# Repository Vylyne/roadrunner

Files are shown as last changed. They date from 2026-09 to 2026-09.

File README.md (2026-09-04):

# Roadrunner: a high resolution filament motion sensor

Preview

## Contents

- [Features](#features)
- [TODO](#todo)
- [Build guide](#build-guide)
- [Klipper installation](#klipper-installation)
- [Configuration](#configuration)
- [Usage](#usage)

## Features

- [x] High-resolution, sub-millimetre motion detection
- [x] Direction detection for extrusion and retraction
- [x] Filament-presence detection and NeoPixel status indication
- [x] UART, I2C, and USB-serial sensor transports
- [x] Klipper runout, under-extrusion, and calibration support
- [x] Persistent provisioned device identities with safe USB diagnostics
- [x] Direct USB maintenance and ROM BOOTSEL recovery
- [x] A board without a valid identity refuses to serve sensor data

Provisioned USB serials use the `RR-<26 base32 UUID>` namespace. An ordinary
UF2 update preserves the identity record; the direct-USB `CLEAR_IDENTITY`
maintenance command is the only way to clear it.

**A Roadrunner serves no sensor data on any transport — I2C, UART, or USB —
until it has a valid identity. This is by design**, not a bug: it is the
invariant that keeps every provisioning path safe to use without its own
hand-written guard (see `docs/roadrunner-identity-gate-design.md`). A board
that is flashed and never provisioned, or whose identity record cannot be
trusted (a conflicting or unreadable record, not only an absent one), is
inert; on I2C and UART it announces this with a short amber LED burst every
30 seconds, and the absence of that burst on the next boot after
provisioning is the confirmation it worked. If your Roadrunner "does not
work" after flashing, provision it first.

Every provisioning path is built on the same firmware primitive: the direct
USB admin `PROVISION_UUID` opcode, which works today on all six firmware
images (see [`docs/roadrunner-usb-admin-protocol.md`](docs/roadrunner-usb-admin-protocol.md)).
There are four intended ways to reach it:

- mcu-updater, opt-in automatic provisioning
- mcu-updater, manual provisioning
- a standalone USB provisioning script (planned; see
  `docs/roadrunner-identity-gate-design.md`)
- the Klippy extra, on connect, when opted in — for an I2C- or UART-wired
  Klipper install, over the board's usbserial admin connection

There is no provisioning write path on I2C or UART yet, so **an I2C-only or
UART-only installation needs a USB cable once**, even when using the Klippy
extra's on-connect path — every route above ultimately goes over USB.

## TODO

- [ ] Add GitHub Actions firmware build and release artifacts, plus repeatable
  protocol validation on a bench board.

Most 3D printer motion sensors are bulky, slow to trigger, prone to false positives, and have a high detection distance meaning a large amount material is extruded before actually detecting a runout, leading to poor layer adhesion and failed prints after a runout.

The Roadrunner motion sensor is based on a magnetic rotary encoder which can detect sub-millimeter movement in the filament for accurate extrusion length measurement, in addition to an IR sensor which can instantly detect filament runout. With the combination of both sensors and a dedicated RP2040-Zero board for collecting data, the Roadrunner can detect which type of issue is affecting a print, between simply reaching the end of a spool, the filament no longer moving, or the filament moving but at a lower than expected rate of extrusion.

By leveraging the higher precision of the sensor, it's possible to determine the length, speed and volumetric flow that are expected and compare them to the actual measured values in real time which gives us a reasonable approximation of _how much_ the filament is being under-extruded by. A simple to use `CALIBRATE_MAX_FLOW` command is provided to perform free-air extrusion tests and automatically benchmark the maximum volumetric flow of any temperature/nozzle/material combination.

## Build guide

This is an open-source project, so you can build your own!

See the [bill of material](manual/BOM.md) and the [assembly manual](manual/ASSEMBLY.md).

## Klipper installation

Clone the repository and create a symlink to the sensor code:

```
cd ~
git clone --depth 1 --single-branch https://github.com/Vylyne/roadrunner.git roadrunner-filament-sensor
~/roadrunner-filament-sensor/install.sh
```

Restart klipper for the new sensor type to be recognized:
```
sudo service klipper restart
```

To get automatic updates within moonraker, add the following block at the end of `moonraker.conf`:
```ini
[update_manager roadrunner-filament-sensor]
type: git_repo
path: ~/roadrunner-filament-sensor
origin: https://github.com/Vylyne/roadrunner.git
install_script: install.sh
primary_branch: main
managed_services: klipper
```

## Configuration

Add the following configuration to your `printer.cfg`:

```
[high_resolution_filament_sensor roadrunner]
extruder: extruder
#  The extruder to which this sensor is attached
uart_rx_pin: P0.0
uart_tx_pin: P0.1
#  TX and RX pins for UART communication, leave out if i2c or USB serial is used (see below).
#i2c_address: 64
#  The address of the sensor on the I2C bus, the default is 64 (0x40). Only
#  change this if you attach more than one sensor on the same I2C bus.
#i2c_mcu: mcu
#  The mcu on which the sensor is connected.
#i2c_bus: i2c1
#  The I2C bus to which the sensor is connected on the mcu.
#serial: /dev/serial/by-id/usb-Raspberry_Pi_Pico_E66130100F655734-if00
#  The serial port over which the sensor is connected. Find with `ls -alh /dev/serial/by-id`.
pause_on_runout: False
#  Whether or not to pause the print automatically when a runout
#  condition is triggered.
runout_gcode: RESPOND TYPE=command MSG='Filament runout detected'
#  The gcode to execute when a runout condition is detected.
invert_direction: False
# If the measured distance/speed values are negative, change this to True.
rotation_distance: 23.4
# The length of filament which corresponds to a full 360 degree rotation
# of the magnet over the rotary encoder. A good starting point is the
# circumference of the BMG gears in the sensor.
underextrusion_max_rate: 0.5
# What rate of underextrusion can be tolerated, as a value between 0.0 and 1.0.
# The rate is calculated by comparing the extruder position to the measured
# filament length over a certain period. A rate of 0.0 means the measured
# filament motion matches the expected extrusion distance over the period.
# A rate of 1.0 means no filament motion was detected at all when some motion
# was expected for the extruder.
underextrusion_period: 5
# How long should the underextrusion rate stay above the max rate before
# a runout is triggered.
hysteresis_bits: 3
# How many bits to ignore from the magnetic rotary encoder's angle data.
# This setting determines the minimum detectable change in position
# for the sensor. Configuring this too low can result in flapping between
# two adjacent positions even when the filament is not moving.
```

Two virtual pins are created for each sensor, which can be used to configure a [`filament_motion_sensor`](https://www.klipper3d.org/Config_Reference.html#filament_motion_sensor) or a [`filament_switch_sensor`](https://www.klipper3d.org/Config_Reference.html#filament_switch_sensor). This is mainly for convenience of use with user interfaces like mainsail/fluid. The virtual motion sensor will be triggered as soon as the sensor moves by the minimum detectable distance. The switch sensor will trigger when the IR sensor detects the filament is present. Both objects will work independently of the runout detection algorithm implemented in `high_resolution_filament_sensor` which considers additional factors such as underextrusion.

An example configuration would look like:

```
[filament_motion_sensor roadrunner_motion]
detection_length: 2
extruder: extruder
switch_pin: virtual_motion_sensor:roadrunner
pause_on_runout: False
runout_gcode: RESPOND TYPE=command MSG='Filament motion sensor detected a runout'
event_delay: 0.1

[filament_switch_sensor roadrunner_switch]
switch_pin: virtual_switch_sensor:roadrunner
pause_on_runout: False
runout_gcode: RESPOND TYPE=command MSG='Filament switch sensor detected filament is no longer present'
event_delay: 0.1
```

## Usage

##### Calibration cheat sheet

Here's an example of a complete calibration workflow:

```
# Disable a few things for these tests
SET_PRESSURE_ADVANCE EXTRUDER=extruder ADVANCE=0
SET_Z_THERMAL_ADJUST TEMP_COEFF=0 ENABLE=0

# Optionally home the printer and move to a safe Z
G32
G0 Z100

# Check your sensor info
QUERY_FILAMENT_SENSOR SENSOR=roadrunner

# Find rotation_distance value, don't forget to save it in the sensor config & restart.
CALIBRATE_FILAMENT_SENSOR_ROTATION_DISTANCE SENSOR=roadrunner TEMP=250 LENGTH=30 SPEED=30 COUNT=10

# Find max flow for this extruder, save the graph of collected data for future reference (THIS WILL TAKE A WHILE)
CALIBRATE_MAX_FLOW SENSOR=roadrunner TEMP=250 START=1 STOP=40 SAVE_GRAPH=1

# Measure a G1 command at a high speed (e.g. 11.5mm/s = 690mm/m).
# Use a value that will produce a flow in the non-linear part of the curve in the previous graph.
FILAMENT_SENSOR_MEASURE SENSOR=roadrunner TEMP=250 SPEED=690 LENGTH=100 SAVE_GRAPH=1

# Enable nonlinear extrusion with coefficients suggested by `CALIBRATE_MAX_FLOW`
ENABLE_NONLINEAR_EXTRUSION SENSOR=roadrunner ENABLE=1 COEFFICIENTS=-0.1106867,1.1197162,-0.0347608,0.0028625

# Take same measurement again, the measured length and speed should show little deviation.
FILAMENT_SENSOR_MEASURE SENSOR=roadrunner TEMP=250 SPEED=690 LENGTH=100 SAVE_GRAPH=1

# Now check the result of the extrusion compensation by generating a new graph (THIS WILL TAKE A WHILE)
CALIBRATE_MAX_FLOW SENSOR=roadrunner TEMP=250 START=1 STOP=40 STEP=2 COUNT=2 SAVE_GRAPH=1
```

##### Calibrate the sensor's rotation distance:

The first thing to do is to calibrate the `rotation_distance` for the sensor itself. This is done
with `CALIBRATE_FILAMENT_SENSOR_ROTATION_DISTANCE`:

```
CALIBRATE_FILAMENT_SENSOR_ROTATION_DISTANCE SENSOR=roadrunner TEMP=250 LENGTH=30 SPEED=60 COUNT=10
```

* `TEMP`: The temperature to heat up the extruder heater at. Default is 200.
* `LENGTH`: The length of filament to retract. Default is 25.
* `SPEED`: The extrusion speed, in rotation per minute (e.g. 300 means 5mm/s). Default is 30 (0.50mm/s).
* `COUNT`: How many times to perform the test. Default is 10.

This macro will heat up the extruder heater to the specified temperature, retract the filament multiple times,
and calculate some stats. The measurement is done while retracting the filament to avoid introducing an error
due to the back-pressure in the nozzle. Make sure a length of filament at least `LENGTH` mm long can
be retracted while still being gripped by the extruder gears. For best results, perform this test at low
speed over a distance long enough for the sensor's gears can do one full rotation.

After the distance measurements are taken, they are sorted by frequency and the measurement with the highest frequency is used to calculate a new `rotation_distance`. For example, if 8/10 measurements read 25.62mm when 25mm was expected, the `rotation_distance`
was too high and a new value is automatically suggested. After saving the new `rotation_distance` in your sensor configuration, repeating the test with the same macro parameters should measure the correct distance. The deviation between measurements is reported relative to the minimum detectable change in position, a small deviation indicates repeatable measurements. While the sensor is
high precision, its accuracy and repeatability over multiple readings can be affected by real world factors such as
springiness in the PTFE tube, the attachement of the sensor to the body of the extruder, etc.

Preview

##### Measure a G1 command

Extrude some filament using a G1 command, and print the result as measured by the sensor.

```
FILAMENT_SENSOR_MEASURE SENSOR=roadrunner TEMP=250 LENGTH=10 SPEED=120 COUNT=1
```

* `TEMP`: The temperature to heat up the extruder heater at. Default is 200.
* `LENGTH`: The length of filament to retract. Default is 10.
* `SPEED`: The extrusion speed, in rotation per minute (e.g. 300 means 5mm/s). Default is 120 (2mm/s).
* `COUNT`: How many times to perform the test. Default is 1.
* With the `SAVE_GRAPH=1` parameter, a graph of all measurements is saved to klipper's current working directory (usually `~/klipper/`).

The macro will run one or more G1 command until the desired length of filament is extruded. The macro will print stats for each move, as measured by the sensor.

Optionally if a graph is saved, the output will look like this:

Preview

##### Max flow calibration

The goal of this macro is to help determine the maximum volumetric flow for a given combination of filament, nozzle and temperature. Before starting, make sure your extruder's `filament_diameter` is correct, as well as the filament sensor's `rotation_distance`. For best results, the `STOP` value should be above or near the top of your extruder's expected maximum volumetric flow rate.

```
CALIBRATE_MAX_FLOW SENSOR=roadrunner TEMP=250 START=1 STOP=50 SAVE_GRAPH=1
```

* `TEMP`: The temperature to heat up the extruder heater at. Default is 200.
* `DURATION`: How long to extrude for during each test, used to determine the extrusion length (length = speed * duration). Default is 10 seconds.
* `START`: The minimum volumetric flow to test. Default is 5.
* `STOP`: The maximum volumetric flow to test. Default is 25.
* `STEP`: The amount by which to increment the volumetric flow between each test. Default is 1.
* `COUNT`: How many times to perform the test for each volumetric flow value. Default is 5.
* `MAX_SPEED_DEVIATION`: The percentage of deviation between the expected and the measured speed that will be considered acceptable. Used for recommending a maximum volumetric flow. Default is 0.05 (5%).
* With the `SAVE_GRAPH=1` parameter, a graph of all measurements is saved to klipper's current working directory (usually `~/klipper/`).

Preview

This macro will warn when a given volumetric flow was so high that not all measurements could be taken at this rate. This often corresponds to the physical limit of the extruder, where the back-pressure is so high that the extruder cannot keep up and eats into the filament.

After the measurements are taken, this macro will look for a range of speeds where the deviation between the expected and measured speeds is below `MAX_SPEED_DEVIATION` percent. At higher speeds, the back-pressure in the nozzle will cause under-extrusion, this can be identified visually in the data graph (use `SAVE_GRAPH=1`) as a part of the curve where the exected and measured speeds start deviating sharply. A polynomial curve is fitted to the relationship between the expected vs measured speeds, which can be used to compensate for the under-extrusion at higher speeds.

Optionally if a graph is saved, the output will look like this:

Preview

##### Enable non-linear extrusion compensation (EXPERIMENTAL)

A `[non_linear_extrusion]` config section must be added for this command to work with a given extruder:
```
[non_linear_extrusion t0]
extruder: extruder
# Name of the extruder for which nonlinear extrusion compensation can optionally
# be enabled.
```

When non-linear extrusion compensation is enabled, the increase in pressure in the extruder will be compensated by increasing the requested speed of G1 commands. This applies to both extrude-only moves as well as regular printing moves. The compensation is only applied when using relative coordinates and only when a positive E distance is specified since retraction moves are not affected by pressure in the nozzle.

```
ENABLE_NONLINEAR_EXTRUSION EXTRUDER=extruder ENABLE=1 COEFFICIENTS=-0.1106867,1.1197162,-0.0347608,0.0028625
```

* `ENABLE`: 1 to enable, 0 to disable
* `COEFFICIENTS`: A list of comma-separated polynomial coefficients.

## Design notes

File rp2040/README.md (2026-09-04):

# Roadrunner RP2040-zero Firmware

## Dependencies

```sh
sudo apt install cmake gcc-arm-none-eabi libnewlib-arm-none-eabi libstdc++-arm-none-eabi-newlib
```

## Configuring

Some neopixels have RGB color ordering while others have GRB. When the filament is inserted the LED should ligth green, if it is RED then you should use the GRB ordering. Uncomment the following line in `neopixel.h` and re-run `make` to build the firmware.

```c
#define GRB_LED_ORDER 1
```

## Building

```sh
git clone https://github.com/Vylyne/roadrunner.git roadrunner-filament-sensor
cd roadrunner-filament-sensor
git submodule update --init --recursive
cd rp2040
mkdir build
cd build
cmake ..
make
```

You'll find multiple `.uf2` files in the `roadrunner-filament-sensor/rp2040/build` directory. The name contains `uart`, `i2c` or `usbserial` for the communication mode between mcu and sensor, and `rgb` vs `grb` for the neopixel type.

## Flashing

1. Connect RP2040-Zero to computer via USB
2. Press `BOOT` and `RESET` at the same time
3. Release `RESET` and 1 second later release `BOOT`
4. A drive named `RPI-RP2` will appear
5. Copy newly built `.uf2` file to the drive to flash the new firmware.

## LED indications

| Condition | Indication |
| --- | --- |
| board has no valid identity (`rr_identity_registers_locked()`) | amber, 50 ms blink half-period, for 1500 ms, repeating every 30000 ms, first burst at power-on |
| `magnet_state != MAGNET_STATE_DETECTED` | blink RED, 100 ms |
| `!filament_present` | solid BLUE |
| otherwise | solid GREEN |

The blink half-periods (50 ms amber, 100 ms RED) assume `CLOCKS_PER_SEC ==
100`, as provided by this toolchain — `neopixel.c` times blinking off its own
`clock()`, which ticks every 10 ms, via
`elapsed_since_blink() = (clock() - last) * 1000 / CLOCKS_PER_SEC`. A
toolchain supplying a different `CLOCKS_PER_SEC` would scale both rates
together, so the 2:1 ratio that makes the amber and RED blinks read as
different channels survives regardless.

The amber burst applies to any board without a valid identity, not only one
that was never provisioned — a conflicting or unreadable identity record
locks the board the same way. It is checked first in the LED chain, so it
overrides the diagnostic indications while active, and yields the LED
entirely between bursts. It exists because the bring-up procedure reads the
LED for minutes at a time — load filament, read BLUE, trim the lever arm,
read BLUE, trim again, until GREEN — so a boot-only announcement would be
missed and a continuous one would fight the readout somebody is actually
using. A short burst on a long period is seen several times without ever
obscuring it.

The first burst is shorter than the rest: firmware init holds a solid RED for
about 1.1 seconds (a 100 ms neopixel settle plus a 1000 ms sensor-init delay)
before the LED chain is reached for the first time, so only the tail of the
first 1500 ms window is visible — roughly 400 ms of amber, not the full
1500 ms. Every burst after that is the complete 1500 ms, since the burst
window is timed from power-on rather than from when the LED chain starts
running.

Because `PROVISION_UUID` resets the board, **the absence of amber on the next
boot is the provisioning success confirmation** — observable with no host, no
tool, and no serial console. For an I2C-only user running an unpatched vendor
extra, that is the entire feedback loop.

## Device identity and USB maintenance

Each image reserves the final flash sector for a persistent Roadrunner device
identity. The ROM BOOTSEL serial and the flash-derived USB ID are diagnostics,
not persistent identities.

Provisioned USB serials use the `RR-<26 base32 UUID>` namespace. An ordinary
UF2 update preserves the identity record; the direct-USB `CLEAR_IDENTITY`
maintenance command is the only way to clear the reserved-sector record. See
[`../docs/roadrunner-usb-admin-protocol.md`](../docs/roadrunner-usb-admin-protocol.md)
for the complete byte-level contract and updater rules.

Maintenance commands are available only over Roadrunner's directly connected
USB CDC port. They are never forwarded over I2C, UART, or a Klipper sensor
transport. The legacy USB sensor-register stream beginning with `0xf5`
continues unchanged.

The maintenance frame is:

```
0x52 0x52 0x01 opcode payload_length payload crc8
```

`crc8` is CRC-8/ATM over every preceding byte (polynomial `0x07`, initial
value `0x00`, no reflection, final XOR `0x00`). `INFO` is opcode `0x01`,
`REBOOT_BOOTSEL` is opcode `0x02`, `PROVISION_UUID` is opcode `0x03`, and
`CLEAR_IDENTITY` is opcode `0x04`; responses set bit `0x80` in the opcode.
The status values are `0x00` OK, `0x01` bad CRC, `0x02` bad length, `0x03`
unprovisioned, `0x04` already provisioned, `0x05` identity conflict, `0x06`
identity-store I/O error, and `0x07` confirmation required. `0x03` is
overloaded: it is both the `INFO` status meaning "no valid identity stored"
and the refusal a locked board returns for an opcode that requires one — see
[`../docs/roadrunner-usb-admin-protocol.md`](../docs/roadrunner-usb-admin-protocol.md#status-03-has-two-roles)
for which opcodes are gated and why `CLEAR_IDENTITY`'s gate is not symmetric
with `REBOOT_BOOTSEL`'s.

An `INFO` request has an empty payload. Its response payload is exactly:

1. status;
2. identity-store state (`0` none, `1` provisioned, `2` conflict, `4` I/O
   error — this reports `rr_identity_load()`'s result; `3` already
   provisioned is part of the enum but is only returned by
   `rr_identity_provision()`, so INFO never reports it);
3. transport (`1` I2C, `2` UART, `3` USB);
4. LED order (`1` RGB, `2` GRB);
5. model length and ASCII model (`roadrunner-v1`);
6. firmware-version length and ASCII version (the CMake
   `ROADRUNNER_FIRMWARE_VERSION`, default `dev`);
7. serial length and ASCII serial; and
8. eight raw flash-UID bytes.

`REBOOT_BOOTSEL` has an empty payload. After the successful ACK is written,
the firmware flushes and waits for TinyUSB's transmit-completion callback and
an empty CDC transmit FIFO, then invokes the RP2040 ROM handoff
`reset_usb_boot(0, 0)`. The same physical USB connection
must then enumerate as the `RPI-RP2` mass-storage device. Copy the matching
UF2 and reconnect to query `INFO` again.

`PROVISION_UUID` has a 16-byte UUID payload. It writes the record only when
the identity store is erased, then returns `OK`, a serial length, and the
new `RR-<26 base32 UUID>` serial. `CLEAR_IDENTITY` has the four-byte ASCII
payload `RRCL`; any other four-byte payload returns `confirmation required`
without changing the store. Successful provision and clear responses are
flushed and transmitted completely before the application resets and the CDC
device re-enumerates. INFO and all error/refusal responses do not reset. On
restart,
the USB descriptor reloads the stored identity and presents the same newly
provisioned serial (or the unprovisioned fallback after a clear).

If the maintenance command is unavailable, use the manual fallback: hold
`BOOT`, press and release `RESET`, release `BOOT` after one second, then copy
the matching UF2 to `RPI-RP2`. Use only a bench RP2040-Zero with a known
recovery path for this procedure.

## Bench validation

On a bench RP2040-Zero, the direct USB BOOTSEL command was verified for the
USB-serial, I2C, and UART images in both RGB and GRB variants. Every image
returned the complete ACK `52 52 01 82 01 00 5a` before the board re-enumerated
as `RPI-RP2`. The USB-serial GRB image also returned a complete legacy
`0xf5 0x10` register-read frame, confirming the maintenance parser preserves
the sensor protocol. Provisioning, clear, UF2-retention, and refusal
behavior were validated against the dedicated bench matrix in the protocol
reference on a recoverable RP2040-Zero on 2026-09-02: all six RGB/GRB
transport images reported the correct INFO transport and LED order, retained
their serial across an ordinary UF2 update, and successfully cleared and
reprovisioned a new serial; both USB-serial images also returned the legacy
`F5 10` response; a duplicate `PROVISION_UUID` was rejected with
`ALREADY_PROVISIONED` on all six images, and a bad clear confirmation was
rejected with `CONFIRMATION_REQUIRED` without rebooting. See
[`../docs/roadrunner-usb-admin-protocol.md`](../docs/roadrunner-usb-admin-protocol.md#bench-matrix)
for the full bench matrix and results.

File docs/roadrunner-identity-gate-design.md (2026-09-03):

# Roadrunner identity gate — design

Status: accepted, 2026-09-03.
Supersedes nothing; extends `roadrunner-provisioning-design.md` and
`roadrunner-usb-admin-protocol.md`, both of which remain authoritative for the
USB admin wire format and the identity namespace.

## Problem

Provisioning today is a policy enforced by hosts, not an invariant enforced by
the device. That policy has to be re-implemented, correctly, in every host that
touches a Roadrunner, and it has already produced four separate hazards:

1. **Flash UID is not unique.** Two Roadrunners built from the same batch report
   the same `pico_get_unique_board_id()`. Their unprovisioned serials therefore
   collide (`RR-UNPROVISIONED-<uid>`), which collides their
   `/dev/serial/by-id/usb-Vylyne_Roadrunner_<serial>-if00` symlinks. udev
   creates one. mcu-updater's `_entry_candidates()` lists that directory by
   name, so with two unprovisioned boards attached it sees **one**, and the
   "refuse ambiguous matches" guard never fires because no ambiguity is visible.
   Confirmed on hardware: provisioning the visible board made the second appear.

2. **Port freedom is not safety.** mcu-updater gates Roadrunner discovery on
   `needs_ports_free = True`. For the USB-serial variant that coincides with
   safety, because Klipper holds the port. For the I2C and UART variants it is
   *inverted*: the USB admin port reads free precisely because Klipper is
   driving the board over a different bus. `PROVISION_UUID` and
   `CLEAR_IDENTITY` both reset the device, so the current code can reset a board
   mid-print.

3. **Provisioning invalidates a `serial:` config line.** A USB-serial variant
   referenced in `printer.cfg` by its by-id path stops resolving the moment its
   serial changes. mcu-updater's `serial_add()` refuses unprovisioned serials,
   but that guard only covers mcu-updater's own registry — a hand-written
   `[high_resolution_filament_sensor]` section is not covered.

4. **"Untracked" carries no information.** Because `serial_add()` structurally
   forbids tracking an unprovisioned board, an unprovisioned Roadrunner is
   always untracked — whether it is on a bench or driving filament on a
   toolhead. mcu-updater's own registry cannot distinguish those cases.

Every one of these is a host compensating for a device that will happily work
without an identity.

## Decision

**A Roadrunner refuses to do its job until it is provisioned.**

The board keeps its autonomous behaviour — it reads the AS5600 and the IR
sensor, and it drives the neopixel. What it refuses is to *answer a host* about
any of it. The identity window and the provisioning path are the only things
available on a host transport until an identity exists.

This is safe to state as an invariant because the Roadrunner is a sensor with no
autonomous actuation. A variant that ever drives something on its own must
revisit it.

### What the invariant buys

- **Unprovisioned implies not live.** No unprovisioned board can be mid-print on
  any transport, so provisioning it can never interrupt one. `assert_printer_idle`
  narrows to what it should always have been: a guard on `CLEAR_IDENTITY` and
  `REBOOT_BOOTSEL` against *provisioned* boards.
- **Hazard 3 disappears at the source.** Nobody can have a working `printer.cfg`
  that references `RR-UNPROVISIONED-…`, because that board never worked.
  Provision-before-configure stops being advice and becomes the only path.
- **Hazard 1 stops mattering for safety.** Colliding unprovisioned serials are
  still a discovery nuisance (see "Still required" below) but no longer a
  correctness risk, because none of the colliding boards is doing anything.
- **All four provisioning paths become safe by construction**, so they can
  coexist without each one needing its own carefully-reasoned guard.

### The four provisioning paths

| Path | Population served | Transport |
| --- | --- | --- |
| mcu-updater, opt-in auto | mcu-updater users | USB admin |
| mcu-updater, manual | mcu-updater users | USB admin |
| `scripts/roadrunner_usb.py` (in mcu-updater) | USB wired, no mcu-updater | USB admin |
| klippy extra, on connect | Klipper-only | usbserial only, until the write path lands |

The USB admin layer is present on all six builds ({I2C, UART, USB} × {RGB, GRB}),
so the first three cover anyone with a USB cable attached.

**Correction, 2026-09-03.** An earlier version of this table claimed the fourth
path serves an I2C-only or UART-only installation with no USB cable, and called
that its reason for existing. That is wrong, and it contradicted this document's
own "Still required" section: neither `i2c_target.c` nor `tmcuart.c` has a write
path, so the klippy extra can provision over usbserial only. **An I2C-only or
UART-only installation needs a USB cable once**, until provisioning writes over
those transports are built. The fourth path still earns its place — it is the
route for a Klipper host with no mcu-updater — but not for the reason first
given.

## Firmware design

### The choke point

All three host transports already funnel through a single function:

```c
void prepare_register_data(uint8_t reg, uint8_t *buf, size_t *length);
```

- `i2c_target.c` calls it from `I2C_SLAVE_REQUEST`.
- `usbserial.c` calls it from `usbserial_send_response()`.
- `tmcuart.c` calls it from `tmcuart_send_response()`.

The gate therefore lives in exactly one place. No transport-specific policy.

### Refuse audibly, never go dark

An I2C target that stops ACKing looks like a wiring fault. A silent TMC-UART
looks like a dead board. Both send someone hunting hardware problems that do not
exist. The transport loops keep running unprovisioned, and a blocked read
**returns a response of the expected length, filled with `0xFF`**.

`0xFF` is out of range for almost every existing field: it is not a defined
`MAGNET_STATE_*`, and `0xFFFFFFFF` is not a plausible angle or turn count. An
unpatched vendor extra therefore reads *visibly broken*, not plausibly wrong —
which is the correct failure. A patched extra reads the identity-state register
and knows exactly why.

**One exception, and it is real:** `state.filament_present` is a `bool`, so
`0xFF` at `READ_FILAMENT_PRESENCE` (`0x22`) is *truthy*. A host reading that
register in isolation on a locked board sees "filament present" — plausibly
wrong, not visibly broken. This is accepted rather than fixed with a
per-register refusal value, because a table of per-field sentinels would be
more code, more to keep in step, and still not authoritative. The mitigations
are that `READ_ALL` carries `magnet_state = 0xFF` in the same payload, which
*is* out of range and which the vendor extra surfaces as `magnet_state`, and
that `READ_IDENTITY_STATE` is the authoritative answer any host is expected to
consult. The protocol doc must state the exception explicitly so nobody
concludes a locked board is reporting real filament.

Zero-length responses are explicitly rejected as a refusal encoding, and so is a
bare status byte: `0x03` collides with `MAGNET_STATE_TOO_STRONG` on a one-byte
register.

### Identity register window

A new register range, chosen to clear the existing sensor map (`0x10`,
`0x20`–`0x24`, with `0x20` reserved for the commented-out `READ_HEALTH`):

| Register | Name | Size | Content |
| ---: | --- | ---: | --- |
| `0x30` | `READ_IDENTITY_STATE` | 1 | `rr_identity_status_t` — 0 none, 1 ok, 2 conflict, 3 already provisioned, 4 I/O error |
| `0x31` | `READ_SERIAL` | 34 | ASCII, NUL-padded. `RR_USB_SERIAL_MAX_LENGTH` is 34; the longest real serial, `RR-UNPROVISIONED-<16 hex>`, is 33 |
| `0x32` | `READ_FIRMWARE_VERSION` | 32 | ASCII, NUL-padded |
| `0x33` | `READ_VARIANT` | 2 | transport byte, LED-order byte — same values as the USB `INFO` payload |
| `0x34` | `READ_FLASH_UID` | 8 | Raw diagnostic bytes. **Hosts must not persist this** |

These five registers are **always readable**, provisioned or not. They are the
unprovisioned allow-list and the steady-state identity source, and one
definition serves both — there is no separate "provisioning mode."

Field order and encoding mirror the USB `INFO` response deliberately, so
`roadrunner-usb-admin-protocol.md` stays the single source of truth for what a
Roadrunner's identity *is*, with `INFO` and this window as two encodings of it.

### Status `0x03` serves two roles

`RR_USB_ADMIN_UNPROVISIONED` (`0x03`) currently documents as "INFO status: no
valid identity is stored" — a state. It now also encodes a refusal, returned by
the USB admin layer for any opcode other than `INFO` and `PROVISION_UUID` while
unprovisioned. The protocol doc must say so, or a host reading `0x03` off a
blocked command misreads it as an `INFO` reply.

`CLEAR_IDENTITY` is refused only when the status is `RR_IDENTITY_NONE` — there
is genuinely nothing to erase. It is **not** gated on `status == RR_IDENTITY_OK`.

**`REBOOT_BOOTSEL` is not gated at all. Correction, 2026-09-03.** An earlier
version of this document put it in the refusal set while unprovisioned, arguing
"there is no reason to reflash a board that cannot be used." That reasoning is
backwards, and following it produced a genuine dead end.

`rr_identity_clear` refuses a conflicted sector outright —
`identity_store.c:74-76` returns `RR_IDENTITY_CONFLICT` before erasing, and
`tests/test_identity_record.c` asserts the sector is left byte-for-byte
unchanged. So a conflicted board cannot be repaired by `CLEAR_IDENTITY`. With
`REBOOT_BOOTSEL` also gated, such a board could do nothing over USB admin at
all: `INFO` answers, `PROVISION_UUID` returns `05`, `CLEAR_IDENTITY` returns
`05`, `REBOOT_BOOTSEL` returned `03`. Every software recovery path was closed.

A board that cannot be used is precisely the one you want to reflash. The gate
had no beneficial case — it fired only on `NONE`, `CONFLICT` and `IO_ERROR`,
and reflashing is the right action in all three. Reflashing is maintenance, not
"doing its job", so it was never inside the invariant this design exists to
enforce; normal UF2 updates preserve the identity sector, so it is not an
identity bypass; and the physical BOOTSEL button meant the gate only ever
blocked the convenient path, never a capable attacker.

The resulting opcode table:

| Opcode | `NONE` | `CONFLICT` | `IO_ERROR` | `OK` |
| --- | --- | --- | --- | --- |
| `INFO` | allowed | allowed | allowed | allowed |
| `PROVISION_UUID` | allowed | refused `05` (store) | store decides | refused `04` |
| `CLEAR_IDENTITY` | refused `03` | admitted, refused `05` by the store | store decides | allowed |
| `REBOOT_BOOTSEL` | allowed | allowed | allowed | allowed |

Note the two-stage behaviour of `CLEAR_IDENTITY`: the opcode gate admits it in
every state but `NONE`, and the *store* then decides. A conflicted sector is
never erased. `RR_IDENTITY_IO_ERROR` is recoverable only when the failure was at
the verify stage with reads still working (`identity_store.c:77-82`); a
read-failure `IO_ERROR` returns at `:70-72` without erasing. **`REBOOT_BOOTSEL`
is therefore the recovery path for a conflicted board**, which is the concrete
reason it must stay ungated.

### LED behaviour

Current main-loop behaviour, unchanged as the steady state:

| Condition | Indication |
| --- | --- |
| `magnet_state != MAGNET_STATE_DETECTED` | blink RED, 100 ms |
| `!filament_present` | solid BLUE |
| otherwise | solid GREEN |

The bring-up procedure depends on this: load filament, read BLUE, trim the lever
arm, read BLUE, trim again, until GREEN. That is an iterative physical fitting
loop lasting minutes with a human watching the LED — so a boot-only
unprovisioned announcement would be missed, and a continuous one would fight the
readout the human is actually using.

**Unprovisioned boards therefore burst amber periodically**: a fast amber blink
(50 ms half-period) for 1500 ms, repeating every 30000 ms, with the first burst
at power-on. Between bursts the diagnostic indication owns the LED completely.
At a 5% duty cycle the fitting loop is never meaningfully obscured, and nobody
works for minutes without seeing several bursts.

The 50 ms rate is deliberately faster than the 100 ms RED magnet blink, so the
two read as different channels rather than as a new sensor state — hue alone is
too weak a signal between amber and red on a WS2812.

Because `PROVISION_UUID` resets the board, **the absence of amber on the next
boot is the success confirmation** — observable with no host, no tool, and no
serial console. For an I2C-only user running an unpatched vendor extra, that is
the entire feedback loop.

## Host design

> **Cross-repo intent, not verified against this tree.** Everything below names
> code in `mcu-updater` and `buffer_manager`, read on 2026-09-03 but not
> reachable from this repository. A firmware reviewer cannot check these
> references and should not try; they are recorded here so the three repos argue
> from one document. Treat any specific symbol name as a pointer to re-verify,
> not as a fact about the current state of those repos. The firmware sections
> above are verifiable in this tree and are binding.

### Klippy extra

`high_resolution_filament_sensor.py` reads the identity window at connect,
caches it (identity is immutable between reboots — it must not ride the 100 ms
`CHECK_RUNOUT_TIMEOUT` path), and publishes `serial`, `firmware_version` and
`variant` through `get_status()`. Moonraker then exposes them in
`printer.objects`, and mcu-updater reads them exactly as it already reads
`print_stats` and `idle_timeout`.

That is what finally answers `tracked_by` for I2C and UART boards: Klipper
states the fact rather than mcu-updater inferring it from a transport byte.

On-connect provisioning, when enabled:

- Opt-in config key on the section, default off. Fires only when that section
  reads unprovisioned; never touches a provisioned board.
- **Provision, then raise a config error** — do not block a klippy connect
  handler waiting on the device reset. The message names the new serial:
  `provisioned RR-…, restart Klipper`.
- For a `serial:`-configured USB variant the message must also name the new
  by-id path, `usb-Vylyne_Roadrunner_<serial>-if00`, because that config line is
  now stale. I2C addresses and UART pins are identity-free and survive
  untouched, which is why only this variant needs the longer message.
- The flow is loop-safe **by the protocol's own refusal rule**: `PROVISION_UUID`
  "never replaces an existing identity, including when the UUID is identical",
  so the restart reads a valid identity and proceeds. A provisioning loop is
  structurally impossible.
- The write path belongs in a helper the extra calls, **not** in
  `high_resolution_filament_sensor.py` itself. That module is vendored from
  `roadrunner-filament-sensor`; keeping the flash write outside it holds the
  vendor patch down to a few lines of read-and-report.

### mcu-updater

- **Discovery must stop enumerating `/dev/serial/by-id` by name.** Use
  `usb.collect()` or `/dev/serial/by-path` so colliding unprovisioned serials
  are still individually addressable. `RoadrunnerDevice.topology` already exists
  for this handoff.
- **Auto-provision is opt-in**, and `auto_provision` belongs in
  `RegistryMethods.LOUD_SETTINGS` alongside `enable_flashing` and
  `allow_flash_while_printing` — "the agent log is the only audit trail there
  is," and this authorizes unattended flash writes.
- **Auto-provision must fail closed.** `assert_printer_idle` deliberately warns
  and continues when the activity query throws, and is short-circuited by
  `allow_flash_while_printing`. Both are right for a flash a human just clicked
  and is watching; both are wrong for an unattended write. Auto-provision
  honours neither escape hatch.
- **Pre-provision printer.cfg check.** Before provisioning a USB-variant board,
  read `configfile.settings` via Moonraker and warn if the board's current by-id
  path appears as a `serial:` value. `CfgDocument` exists if the rewrite is
  offered.
- **Row labelling.** A row whose identity window reports transport I2C or UART
  should say so. Those boards render as untracked while being driven by the
  printer, and the row is the only place that can correct the impression.

### BOOTSEL closed loop

Separate work, unblocked by this design but not part of it. Notes so they are
not rediscovered:

- `REBOOT_BOOTSEL` (`0x02`) already exists in the admin protocol.
- Flash UID **cannot** correlate a board across the reboot — it is not unique.
  Topology is the only key. `/dev/disk/by-path` ↔ `/dev/serial/by-path`, matched
  on the USB port prefix: the CDC path ends `…usb-0:1.2:1.0` while the MSC path
  ends `…usb-0:1.2:1.0-scsi-0:0:0:0`, so the match is prefix-normalized, never
  string equality.
- The udev rule hardcodes `/media/%USER%/RPI-RP2`, so a second BOOTSEL board
  loses. Mount at `/media/%USER%/BOOTSEL/by-path/$env{ID_PATH_TAG}` instead —
  `ID_PATH_TAG` is the filename-safe variant, and the rule installs as
  `99-mcu-updater-bootsel.rules`, after `60-persistent-storage.rules`, so it is
  populated. `bootsel_scan()` then globs and leans on its existing
  `INFO_UF2.TXT` marker check, which stops being belt-and-braces and becomes the
  only thing distinguishing a real bootloader volume.
- That removes `_find_mount()`'s ">1 volume" refusal, which today also fires
  when an unrelated spare Pico is attached.
- `Bootsel.needs_services_stopped` flips to `True` — its own comment predicts
  this — and `settled()` becomes a real wait, because the returning serial is
  finally knowable.
- `flashers/bootsel.py`'s `target_for()` claims the flash UID records "a real
  identity". That claim is false and goes with the rest.

## Still required, and explicitly not solved here

- **Provisioning writes over I2C and UART.** The identity window is read-only in
  this design, and `i2c_target.c` currently discards all writes ("we do not
  support I2C writes"). Until a write path exists, the klippy extra can
  provision over usbserial only, and an I2C-only or UART-only installation still
  needs a USB cable once. This is deliberately deferred: the read window is the
  harder decision and the easier build, and the write path benefits from the
  register map already existing.
- **The `scripts/roadrunner_usb.py` gap.** It is stdlib-only at the top level
  and speaks the protocol directly, but "deliberately neither scans ports nor
  creates identities" — today it needs mcu-updater to hand it a port and a UUID.
  A port scan and a `--generate` flag turn it into the one-file provisioning
  tool the README can point at, which is what makes the firmware's hard
  dependency on a provisioning host acceptable.
- **Upstreaming.** The identity fields in `get_status()` are a patch to a
  vendored module. Carrying it forever or upstreaming it is a decision to make
  deliberately, not at the next vendor sync.
- **A model register.** The USB `INFO` payload carries a model field
  (`roadrunner-v1`), and this document's own "Identity and updater rules" require
  an updater to validate it. The register window has no equivalent, so a host
  reading identity over I2C or UART cannot perform that validation. Deferred to
  the klippy-extra plan rather than added speculatively: the model string is
  file-static in `usb_admin.c`, so exposing it means hoisting it across a module
  boundary, and that encoding is better chosen once a real consumer defines what
  it needs. Until then, model validation is available only over USB.

## Accepted costs

A board flashed with this firmware and never provisioned is inert. That is the
point, but it lands hardest on someone running this firmware with the unpatched
vendor extra and no USB cable, who gets a board that never works. The amber
burst and the standalone script are the two mitigations; both need to be
documented prominently in the README, not just in this file.

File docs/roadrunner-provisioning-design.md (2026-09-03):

# Roadrunner provisioning and identity-maintenance design

## Purpose

This design adds explicit, direct-USB provisioning and identity clearing to
Roadrunner. It completes the path from a blank identity sector to an
independently discoverable board without making ordinary discovery or firmware
updates mutate identity.

## Identity presentation

The persistent identity is exactly a raw, host-generated, random 16-byte UUID.
It is stored only in the two existing validated identity records.

`RR-` is a non-versioned display namespace. Firmware renders a provisioned
UUID as `RR-` followed by 26 uppercase Crockford-base32 characters. A blank
board renders `RR-UNPROVISIONED-` followed by its eight-byte flash UID in
uppercase hexadecimal. The flash UID is diagnostic only: it is never stored
by mcu-updater as the board identity and never used to select a write.

These values are deliberately distinct:

- `RRID` / identity-record format `1` version the on-flash record;
- admin-frame version `0x01` versions the maintenance wire format;
- `roadrunner-v1` identifies the hardware design in INFO; and
- `RR-` namespaces a human-readable serial and contains no version.

USB descriptors and INFO use the same serial formatter.

## Direct-USB protocol additions

All maintenance traffic remains available only on Roadrunner's direct USB CDC
port. The existing frame remains:

```c
0x52 0x52 0x01 opcode payload_length payload crc8
```

CRC is CRC-8/ATM over all preceding bytes. Existing INFO (`0x01`) and
REBOOT_BOOTSEL (`0x02`) keep their current meaning. New requests are:

| Opcode | Name | Payload | Success response | Effect |
| --- | --- | --- | --- | --- |
| `0x03` | `PROVISION_UUID` | exactly 16 raw UUID bytes | status, serial length, rendered serial | writes a blank identity sector, then application-reboots |
| `0x04` | `CLEAR_IDENTITY` | ASCII `RRCL` | status | erases the identity sector, then application-reboots |

Responses set opcode bit `0x80`. Successful provisioning and clear responses
are sent and their transmit completion is observed before an application reset
and CDC re-enumeration. `REBOOT_BOOTSEL` instead enters the ROM BOOTSEL
handoff and re-enumerates as `RPI-RP2`; INFO and all error/refusal responses do
not reset. `CLEAR_IDENTITY` uses a fixed four-byte confirmation to prevent an
empty or malformed request from clearing identity accidentally; it is not an
authentication mechanism.

New status values are:

| Value | Name | Meaning |
| --- | --- | --- |
| `0x04` | `ALREADY_PROVISIONED` | a valid identity already exists; provision did not write |
| `0x05` | `IDENTITY_CONFLICT` | two valid but different records exist; no mutation occurred |
| `0x06` | `STORE_IO_ERROR` | erase, program, or verification failed; no success is claimed |
| `0x07` | `CONFIRMATION_REQUIRED` | `CLEAR_IDENTITY` payload was not exactly `RRCL` |

The existing status values retain their meanings. Bad payload lengths return
`BAD_LENGTH` (`0x02`). Provisioning is allowed only when the store reports no
valid identity. It never replaces an existing identity, even when the supplied
UUID matches it. Clearing is an explicit physical-maintenance operation;
ordinary UF2 updates retain the reserved sector.

## mcu-updater lifecycle

Discovery is read-only. It recognizes a candidate only when both the USB
descriptor and an INFO response agree that it is an unprovisioned Roadrunner.
The resolved USB path is a transient handoff address only.

The untracked-device row exposes **Provision Roadrunner**. After confirmation,
the agent locks the device, generates its UUID with Python's
`secrets.token_bytes(16)`, sends `PROVISION_UUID`, receives the successful ACK,
and waits for the same physical USB connection to re-enumerate. It then sends
INFO again and requires the expected `RR-` serial before releasing the lock.
The board is left visible as a provisioned, untracked Roadrunner; no type,
firmware definition, or persistent registry entry is created automatically.

**Clear identity** is likewise explicit. The agent sends `CLEAR_IDENTITY` only
after user confirmation, waits for re-enumeration, verifies the unprovisioned
INFO state, and leaves the device untracked. Automatic provisioning is not a
default behavior; it may be introduced later as an explicit setting.

## Refusal and recovery rules

- Refuse a candidate whose descriptor, INFO model, protocol version, or
  identity state is inconsistent.
- Refuse if more than one candidate matches an action request.
- Refuse a successful ACK followed by a missing, mismatched, or still
  unprovisioned re-enumeration.
- Do not persist the flash UID or the physical path as board identity.
- On timeout or error, report the last confirmed state and require a fresh
  discovery; do not retry a write blindly.
- Manual BOOTSEL remains the recovery path for an interrupted firmware update.
  A failed provisioning or clear operation must not make the normal application
  flash region inaccessible.

## Verification

The exact byte-level contract is maintained in
[`roadrunner-usb-admin-protocol.md`](roadrunner-usb-admin-protocol.md).

Firmware host tests cover valid and invalid provision/clear frames, every
store result, exact response bytes, identity serial rendering, and the
ACK-to-reset ordering. Firmware builds must link all six RGB/GRB transport
images.

Bench validation uses only a recoverable RP2040-Zero. The 2026-09-02 run
covered initial unprovisioned INFO; provisioning and descriptor/INFO transition
to `RR-`; ordinary UF2 retention; rejection of a second provisioning request;
clear and reprovisioning; bad-clear rejection without reboot; manual BOOTSEL
recovery; and legacy USB reads. Interrupted record-write behavior remains
covered by host tests rather than bench fault injection. mcu-updater tests
cover discovery classification, UUID generation, the confirmed physical-path
handoff, re-enumeration mismatch refusal, and leaving successful devices
untracked.

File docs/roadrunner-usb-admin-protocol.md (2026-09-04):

# Roadrunner direct USB administration protocol

This document is the wire-level contract for the Roadrunner direct USB CDC
maintenance endpoint. It is independent of the sensor data protocols carried
over I2C, UART, and the legacy USB stream.

## Framing

Every request and response has this form:

```text
52 52 01 opcode payload_length payload... crc8
```

The two `52` bytes are the sync marker. Version `01` is the administration
protocol version. `payload_length` is one byte and must be at most 64 for a
request. CRC-8/ATM is calculated over every byte before the CRC byte, with
polynomial `07`, initial value `00`, no reflection, and final XOR `00`.

Responses copy the request opcode with bit `80` set. A response payload starts
with a one-byte status. A malformed frame receives a response for the parsed
opcode when possible; no state-changing operation is performed unless the
complete frame and CRC are valid.

The empty requests are:

```text
INFO:            52 52 01 01 00 90
REBOOT_BOOTSEL: 52 52 01 02 00 AF
```

`PROVISION_UUID` and `CLEAR_IDENTITY` successful responses cause an
application reset after the complete response is sent, the CDC transmit queue
is flushed, and transmit completion is observed; the device then
re-enumerates as its application CDC device. A successful `REBOOT_BOOTSEL`
response follows the same ACK-completion rule but enters the RP2040 ROM
BOOTSEL handoff and re-enumerates as the `RPI-RP2` mass-storage device. `INFO`
and every error or refusal response do not reset.

## Opcodes and status values

| Request | Opcode | Request payload | Successful response payload |
| --- | ---: | --- | --- |
| `INFO` | `01` | empty | INFO payload below |
| `REBOOT_BOOTSEL` | `02` | empty | `00` |
| `PROVISION_UUID` | `03` | exactly 16 raw UUID bytes | `00`, serial length, serial bytes |
| `CLEAR_IDENTITY` | `04` | exactly `52 52 43 4C` (`RRCL`) | `00` |

The status byte values are:

| Value | Name | Meaning |
| ---: | --- | --- |
| `00` | `OK` | Operation succeeded |
| `01` | `BAD_CRC` | Frame CRC did not match |
| `02` | `BAD_LENGTH` | Opcode payload length was invalid, or exceeded 64 |
| `03` | `UNPROVISIONED` | INFO status: no valid identity is stored, **or** refusal: this opcode requires a valid identity |
| `04` | `ALREADY_PROVISIONED` | Provisioning was refused because an identity exists |
| `05` | `IDENTITY_CONFLICT` | Two valid identity records disagree |
| `06` | `STORE_IO_ERROR` | Flash erase, program, or verification failed |
| `07` | `CONFIRMATION_REQUIRED` | Clear payload was not exactly `RRCL` |

`PROVISION_UUID` is accepted only when the identity store is unprovisioned.
It never replaces an existing identity, including when the UUID is identical.
`CLEAR_IDENTITY` is an explicit maintenance action and erases the reserved
identity sector only after the confirmation payload matches exactly.

### Status `03` has two roles

`03` (`UNPROVISIONED`) is overloaded, and a host must not confuse its two
shapes. As an **INFO status**, it is byte 0 of a full, multi-field INFO
payload (see below) — it means "no valid identity is stored," not a refusal.
As a **refusal**, it is the entire response payload: a single status byte,
returned instead of an opcode's normal successful payload, meaning "this
opcode requires a valid identity and was not performed." A host that reads
`03` must first check which opcode the response echoes; only an `INFO` reply
carries the longer shape.

The opcode gate, by identity-store state:

| Opcode | `NONE` | `CONFLICT` / `IO_ERROR` | `OK` |
| --- | --- | --- | --- |
| `INFO` | allowed | allowed | allowed |
| `PROVISION_UUID` | allowed | allowed (store decides) | refused `04` |
| `CLEAR_IDENTITY` | refused `03` | allowed (store decides) | allowed |
| `REBOOT_BOOTSEL` | allowed | allowed | allowed |

`REBOOT_BOOTSEL` is not gated on identity status at all. An earlier revision
refused it unless the status was exactly `OK`, on the reasoning that there is
no reason to reflash a board that cannot be used. That reasoning was
backwards: a board that cannot be used over USB admin is precisely the one
that needs reflashing, and a conflicted board (see below) has no other
software recovery path. Reflashing is maintenance, not the sensor-serving
behaviour the identity gate protects, and normal UF2 updates preserve the
identity sector, so allowing `REBOOT_BOOTSEL` unconditionally is not an
identity bypass.

`CLEAR_IDENTITY`'s gate is asymmetric with the other opcodes: it is refused
only when the status is `NONE` — there is genuinely nothing to erase. For
every other status the opcode is *admitted*, but the identity store still
decides whether it can actually clear:

- **`CONFLICT` is never recoverable by clear.** The store refuses to erase a
  sector it cannot safely interpret, so `CLEAR_IDENTITY` returns `05`
  (`IDENTITY_CONFLICT`) and leaves the sector byte-for-byte unchanged.
  `REBOOT_BOOTSEL` — unconditionally allowed, as above — is the recovery path
  for a conflicted board.
- **`IO_ERROR` is sometimes recoverable.** A failure while re-reading the
  sector to verify a successful erase reaches the erase step and may still
  clear the record. A failure while reading the sector in the first place
  does not reach the erase step at all, and returns `06` (`STORE_IO_ERROR`)
  with nothing changed. A host cannot tell these apart from the response
  alone; retrying `CLEAR_IDENTITY` is reasonable, and `REBOOT_BOOTSEL` remains
  available regardless.

## INFO response

The INFO response payload fields occur in this order:

| Field | Size | Values / encoding |
| --- | ---: | --- |
| status | 1 | `00` when provisioned, otherwise `03` |
| identity-store state | 1 | `0` none, `1` provisioned, `2` conflict, `3` already provisioned, `4` I/O error |
| transport | 1 | `1` I2C, `2` UART, `3` USB |
| LED order | 1 | `1` RGB, `2` GRB |
| model length + model | 1 + up to 13 | ASCII `roadrunner-v1` |
| firmware version length + version | 1 + up to 32 | ASCII, normally CMake `dev` |
| serial length + serial | 1 + up to 33 | ASCII serial namespace below |
| flash UID | 8 | Raw diagnostic bytes, not identity |

The maximum INFO payload is 93 bytes with the current field limits (and is
within the 96-byte response limit). Integers are unsigned bytes; strings are
not NUL-terminated in the frame.

## Identity register window

A fixed range of registers exposes the same identity fields as `INFO`,
directly on the sensor transport itself:

| Register | Name | Size | Content |
| ---: | --- | ---: | --- |
| `0x30` | `READ_IDENTITY_STATE` | 1 | `rr_identity_status_t` — `0` none, `1` ok, `2` conflict, `4` I/O error (this register reports `rr_identity_load()`'s result; `3` already provisioned is part of the enum but is only returned by `rr_identity_provision()`, so it is never observable here) |
| `0x31` | `READ_SERIAL` | 34 | ASCII, NUL-padded |
| `0x32` | `READ_FIRMWARE_VERSION` | 32 | ASCII, NUL-padded |
| `0x33` | `READ_VARIANT` | 2 | transport byte, LED-order byte |
| `0x34` | `READ_FLASH_UID` | 8 | Raw diagnostic bytes |

These five registers are readable over I2C, UART, and usbserial, whether or
not the board is provisioned — they are both the unprovisioned allow-list and
the steady-state identity source. Field order and encoding mirror the USB
`INFO` payload deliberately, so this document stays the single definition of
what a Roadrunner's identity is, with `INFO` and this window as two
encodings of it.

**The identity register window is read-only in this release.** There is no
write path on I2C or UART: `i2c_target.c` reads and discards every byte after
the register address, and the UART transport is request/response only. A
board with no USB cable attached can be read over I2C or UART, but it can
only be provisioned over the direct USB admin protocol above.

`READ_FIRMWARE_VERSION` (`0x32`) is 32 bytes **including** the NUL
terminator, so it holds at most 31 characters of version string — one fewer
than the unterminated 32-byte version field `INFO` can carry. A 32-character
version therefore survives `INFO` intact but truncates to 31 characters in
the register. This is a known, accepted divergence between the two
encodings, not a bug.

Hosts must not persist the flash UID (`0x34`) as an identity; it is a
diagnostic value only and is not guaranteed unique across boards from the
same batch.

### The gate on every other register

While the board has no valid identity — `READ_IDENTITY_STATE` is anything
other than `1` (`OK`), which includes `CONFLICT` and `IO_ERROR`, not only
`NONE` — every register outside the identity window (`0x30`–`0x34`) returns
its normal length filled with `0xFF`. A host must read `READ_IDENTITY_STATE`
(`0x30`) to distinguish a locked board from a genuine sensor fault — `0xFF`
is out of range for almost every field, so an unpatched host reads visibly
broken rather than plausibly wrong.

**One exception:** `state.filament_present` is a `bool`, so `0xFF` at
`READ_FILAMENT_PRESENCE` (`0x22`) is *truthy*. A host reading that register
in isolation on a locked board sees "filament present" — plausibly wrong,
not visibly broken, which is the opposite of what the refusal encoding is
meant to achieve. This is accepted rather than fixed with a per-register
sentinel table, because that would be more code, more to keep in step, and
still not authoritative. Two mitigations exist: `READ_ALL` carries
`magnet_state = 0xFF` in the same payload, which *is* out of range for every
defined `MAGNET_STATE_*`, and `READ_IDENTITY_STATE` (`0x30`) is the
authoritative answer any host is expected to consult. No host should
conclude a locked board is reporting real filament from `0x22` alone.

The board never returns a zero-length response, provisioned or not. Silence
is indistinguishable from a wiring fault on I2C or a dead board on
TMC-UART, so a blocked read always answers at its normal length. Separately,
over I2C a read that runs past a register's payload returns `0x00` filler —
that is the transport's end-of-payload behaviour, distinct from the `0xFF`
refusal encoding, and the two never occupy the same byte position.

## Identity and updater rules

A provisioned serial is `RR-` followed by 26 uppercase Crockford-base32
characters encoding the 16-byte UUID. An unprovisioned device reports the
diagnostic serial `RR-UNPROVISIONED-` followed by the eight-byte flash UID in
uppercase hexadecimal. The UUID is generated by the host with a cryptographic
random source and stored in the reserved final flash sector. The flash UID is
never used as the persistent identity.

The updater must validate the descriptor and INFO model `roadrunner-v1`, keep
the USB path only as a transient physical-path handoff, and refuse ambiguous
matches or mismatched re-enumeration. It must not persist the flash UID or
physical path, automatically adopt a device, or automatically provision one.
After a confirmed manual provision or clear, the device remains untracked.
Normal UF2 updates preserve the identity sector. ROM BOOTSEL is the manual
recovery path if an update or maintenance operation is interrupted.

## Legacy USB compatibility

The administration parser is present on every USB-serial image, including
images whose sensor transport is I2C or UART. Bytes that do not form an admin
frame continue to the legacy sensor stream. A legacy register read begins with
`F5 10` and remains unchanged.

## Bench matrix

The following is the required recoverable-bench validation for provisioning:

1. Record INFO and the unprovisioned descriptor.
2. Send a known 16-byte UUID; receive the complete successful ACK before disconnect.
3. Confirm the re-enumerated descriptor and INFO contain the expected `RR-` serial.
4. Flash a normal UF2 and confirm the serial is retained.
5. Send a second provision request and confirm `ALREADY_PROVISIONED`.
6. Clear with `RRCL`; confirm the unprovisioned descriptor and INFO return.
7. Send a bad clear confirmation and confirm `CONFIRMATION_REQUIRED` without reboot.
8. Verify manual BOOTSEL recovery and repeat a legacy `F5 10` read on USB serial.

Bench validation completed on a recoverable RP2040-Zero on 2026-09-02. All
six RGB/GRB transport images reported the correct INFO transport and LED
order, retained the current serial across the next ordinary UF2 update, and
successfully cleared and reprovisioned a new serial. Both USB-serial images
also returned the legacy `F5 10` response. A second `PROVISION_UUID` was
rejected with `ALREADY_PROVISIONED` on all six images; a bad clear confirmation
was rejected with `CONFIRMATION_REQUIRED` without rebooting.

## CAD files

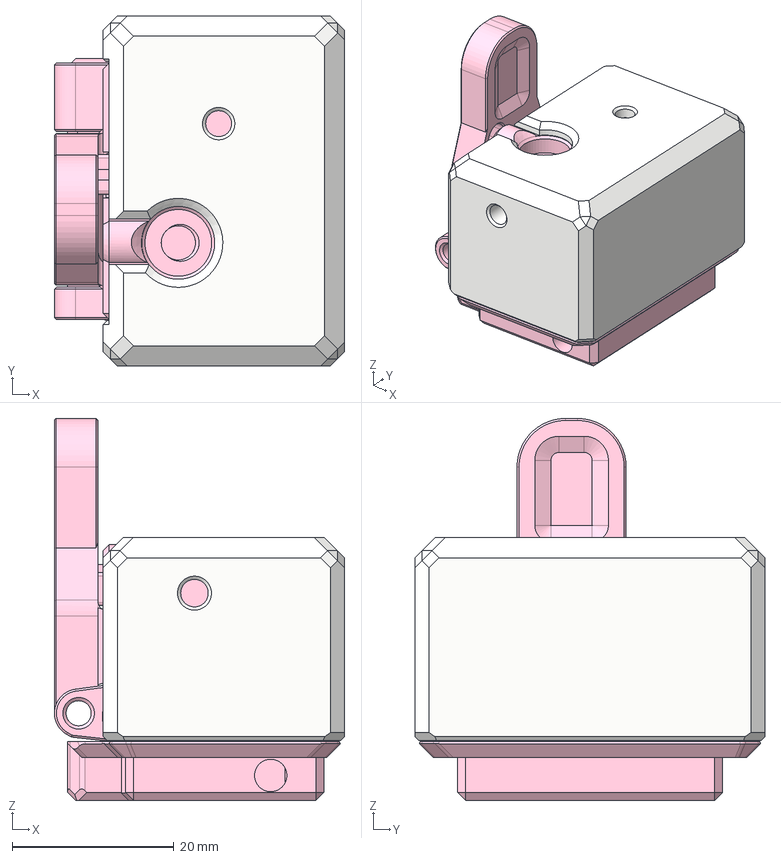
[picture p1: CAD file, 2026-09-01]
CAD/Roadrunner_body-6pin jst-ph.step
35.9 x 43.3 x 47.2 mm
wire_cover
body_part_a
M5Screw in Connector
eacs
idler
magnet_holder
[a]_cover

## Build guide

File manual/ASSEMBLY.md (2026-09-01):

# Roadrunner assembly manual

Gather all parts from the [bill of materials](BOM.md) before getting started.

### 1. Heat-set inserts

Add the heat-set inserts into `body_part_a.stl` and `body_part_b.stl`.



There is one last insert on the top not pictured below:





### 2. Idler assembly



Assemble `idler.stl` together with the idler gear, needle bearings, and the 3x20mm shaft.



### 3. Main body assembly

Add the 5mm bearings into `body_part_a.stl` and `body_part_b.stl`.



Assemble the 5mm shaft, 3x2 magnet and magnet holder parts.



Fit the 5mm shaft into the bearing before adding the AS5600 board.



Tighten the AS5600 board using M3 x 6mm BHCS screws, the 4-pin header should be aligned with the opening on the left. Make sure the 5mm shaft can spin freely once the screws are tight.



Add the drive gear to the 5mm shaft, take care to tighten the setscrew (with loctite). Add the 3x30mm shaft as well.



Complete the main body assembly by sliding the idler onto the 3mm shaft, screw the body A and B parts together using two M3 x 16mm SHCS.



### 4. Electronics

The next step is to solder the electronics as shown here:



Prepare the IR sensor by removing the 3-pin 0.1" header from the board.



Add the 2mm self-tapping screw and make sure the IR sensor lines up with the idler arm.



Prepare the RP2040-Zero and a 4-pin segment of 90-degree 0.1" header. The middle 2 pins should be removed since they are not connected straight between the two boards (we will solder them in reverse later).



Line up the 90-degree header with both boards and solder in place. Pay attention to solder on pins 9 and 12 (it's easy to be off-by-one and solder on the wrong pins).



You should be able to remove both circuit boards together at this point. The middle two pins on the connector are still unsoldered, this is normal.



With the RP2040 set aside, solder some thin wires to the IR sensor board.



Add the RP2040 and AS5600 boards back in place, and cut the IR sensor wires to length.



The red (5V) and black (GND) wires should reach the bottom edge of the PCB, and the brown (middle) wire should reach the GP0 pin. There is a pocket between the two boards for the extra wire length to fit in.



Add two wires between the RP2040 pins GP10/GP11 and the AS5600 pins SDA/SCL. Note that the I2C pin order on the two boards are reversed so the wires should cross each other!



Solder the VCC and GND pads on the AS5600 board to the 3V3 and GND pads on the RP2040. The AS5600 board can be powered by 5V only if the 0Ω resistance (R1) is removed!



Add the female JST-XH header to `wire_cover.stl`, and solder wires to the connector. The red (5V) and black (GND) wires are soldered to the RP2040 5V and GND pads, the green and blue wires are soldered to the RP2040 GP4/GP5 pads.



Make sure you solder on the correct pads as pictured. The numbering starts at 0 and the silkscreen alignment can be misleading.



Fit the wires into the channel built into the wire cover, make sure the wires aren't getting pinched.



Add the M3 x 6mm BHCS and M3 x 10mm BHCS to the secure wire cover.



Push the wires neatly snug together, without covering the RP2040 buttons or the LED.



### Flashing and testing

Now is time to flash the RP2040 and test your work!

1. Head over to the [releases](https://github.com/EiNSTeiN-/roadrunner-filament-sensor/releases) page.
2. Download the firmware for your configuration, for example `roadrunner_v1_uart_rgb.uf2`.
3. Connect RP2040 to your computer with a USB cable.
4. Press the `BOOT` and `RESET` buttons together, release the `RESET` button, and 1 second later release the `BOOT` button.
5. A drive named `RPI-RP2` will appear on your computer
6. Copy the `.uf2` file to the `RPI-RP2` drive, the RP2040 will reboot and the LED will light up.

##### Communication over USB, UART or I2C?

Serial over USB, UART and I2C firmwares are available to provide options for all MCUs and toolhead boards. There's pros and cons to both, the main ones are listed below:

**Serial over USB:**
* Pro: More convenient for some configurations (no wiring required).
* Con: Does not work when the sensor is connected to a toolhead board or the host does not have a USB port available.

**UART:**
* Pro: Good option for MCUs with limited number of pins or without native I2C support. I2C SDA/SCL pins are often special-purpose pins whereas any GPIOs can be used for UART TX/RX.
* Con: The protocol is implemented using bitbang, which is all-around less efficient compared to MCUs that have native I2C support.
* Con: It's only possible to read 4 bytes at a time over UART, so multiple reads are necessary for every update from the sensor, leading to increased communication overhead.
* Con: The implementation is more prone to errors during communication with the RP2040, leading to even greater communication overhead due to retries.

**I2C:**
* Pro: Can be daisy-chained to attach multiple sensors using only 2 pins (requires re-compiling the firmware to get unique I2C IDs).
* Pro: Can read all data from sensor in one go, which lowers the overhead between the MCU and the host.
* Pro: During testing, I2C was less prone to communication failures than UART.
* Con: I2C errors are unrecoverable. In case the RP2040 stops responding or there are delays on the i2c bus for any reason, the printer will perform an emergency stop with an `i2c timeout` error.

If you have available pins on your MCU, I2C is recommended. Otherwise use UART.

##### Flashing red LED (wiring issues)

The LED will flash red when there is an error with the AS5600 board:



Possible reasons for this state include:
1. The AS5600 is not responding over the I2C bus.
2. The magnet is too weak, too strong or not detected at all.

If you assembled the sensor correctly, the magnet should be in the correct place, so the most likely reason for this error is an issue with the wiring for the AS5600 board.

##### Solid red, green or blue LED

If everything is soldered correctly, moving the idler into and out of the IR sensor should toggle the LED between blue and green.

Troubleshooting:
1. If the LED stays the same color when the IR sensor is obstructed, the IR sensor may be soldered incorrectly.
2. If the LED switches between red and blue instead of green and blue, you may have a RP2040-Zero clone with an GRB neopixel. Simply flash the GRB firmware variant and that should fix the issue.

Once the lever arm can be actioned by hand, test with a piece of filament. Trim the lever arm slightly so inserting the filament will push the arm out of the way of the IR sensor, and removing the filament will obstruct the sensor.



Once everything is done, your sensor should work!



### Final touches

Add the cover, printed in your favorite accent color.



Add the PC4-M5 fittings on top and bottom.



Lastly, add the spring assembly



Your sensor is completed!

### Connect to printer

Connection to the printer is dependent on which board the sensor will be connected to. Check the [wiring manual](./WIRING.md) for information on how to connect the sensor to your toolhead board or your printer controller board.

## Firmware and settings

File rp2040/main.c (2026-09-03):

/**
 * Copyright (c) 2020 Raspberry Pi (Trading) Ltd.
 *
 * SPDX-License-Identifier: BSD-3-Clause
 */

#include <stdlib.h>
#include <string.h>
#include <time.h>

#include "pico/stdlib.h"
#include "hardware/clocks.h"
#include "hardware/watchdog.h"
#include "pico/unique_id.h"
#include "tusb.h"

#include "neopixel.h"
#include "as5600.h"
#include "ir_sensor.h"
#include "tmcuart.h"
#include "i2c_target.h"
#include "usbserial.h"
#include "identity_store.h"
#include "usb_admin.h"
#include "identity_registers.h"

void rr_usb_descriptors_init(const struct rr_identity_store *store);

static struct rr_identity rr_usb_admin_identity;
static uint8_t rr_usb_admin_flash_uid[RR_USB_ADMIN_FLASH_UID_SIZE];

#if defined(USB_SERIAL_COMMS) && USB_SERIAL_COMMS
static void rr_usb_admin_legacy_byte(void *context, uint8_t byte)
{
    (void)context;
    usbserial_receive_byte(byte);
}
#endif

static void rr_usb_admin_reboot_application(void *context)
{
    (void)context;
    watchdog_reboot(0, 0, 0);
    while (true) {
        tight_loop_contents();
    }
}

static void rr_usb_admin_init_for_firmware(
    const struct rr_identity_store *identity_store)
{
    pico_unique_board_id_t board_id;
    struct rr_usb_admin_config config = {
        .identity_status = rr_identity_load(identity_store, &rr_usb_admin_identity),
        .identity = &rr_usb_admin_identity,
        .identity_store = identity_store,
        .flash_uid = rr_usb_admin_flash_uid,
#if defined(IS_I2C_TARGET) && IS_I2C_TARGET
        .transport = RR_USB_ADMIN_TRANSPORT_I2C,
#elif defined(USB_SERIAL_COMMS) && USB_SERIAL_COMMS
        .transport = RR_USB_ADMIN_TRANSPORT_USB,
#else
        .transport = RR_USB_ADMIN_TRANSPORT_UART,
#endif
#if defined(GRB_LED_ORDER) && GRB_LED_ORDER
        .led_order = RR_USB_ADMIN_LED_GRB,
#else
        .led_order = RR_USB_ADMIN_LED_RGB,
#endif
        .firmware_version = ROADRUNNER_FIRMWARE_VERSION,
        .reboot_application = rr_usb_admin_reboot_application,
#if defined(USB_SERIAL_COMMS) && USB_SERIAL_COMMS
        .legacy_byte = rr_usb_admin_legacy_byte,
#endif
    };

    pico_get_unique_board_id(&board_id);
    memcpy(rr_usb_admin_flash_uid, board_id.id, sizeof(rr_usb_admin_flash_uid));

    {
        struct rr_identity_registers_config register_config = {
            .identity_status = config.identity_status,
            .identity = config.identity,
            .flash_uid = config.flash_uid,
            .transport = config.transport,
            .led_order = config.led_order,
            .firmware_version = config.firmware_version,
        };
        rr_identity_registers_init(&register_config);
    }

    rr_usb_admin_init(&config);
}

//#define IS_I2C_TARGET 1 // uncomment for i2c communication with printer
//#define USB_SERIAL_COMMS 1 // uncomment for serial over usb communication with printer

#define READ_ALL                    0x10
// #define READ_HEALTH                 0x20
#define READ_MAGNET_STATE           0x21
#define READ_FILAMENT_PRESENCE      0x22
#define READ_FULL_TURNS             0x23
#define READ_ANGLE                  0x24

#define MAGNET_STATE_UNKNOWN        0
#define MAGNET_STATE_NOT_DETECTED   1
#define MAGNET_STATE_TOO_WEAK       2
#define MAGNET_STATE_TOO_STRONG     3
#define MAGNET_STATE_DETECTED       4

// #define HEALTH_UNKNOWN                 -1
// #define HEALTH_OK                       0
// #define HEALTH_AS5600_READ_FAILED       1

#define UPDATE_INTERVAL_MS 10

struct state_t {
    // uint8_t health;

    uint8_t magnet_state;
    bool filament_present;

    int32_t full_turns; // number of times the magnet has crossed the zero point
    int32_t angle; // current angle value
} __attribute__((packed)) state;

clock_t last_update;

bool update_magnet_state()
{
    uint8_t detected, too_weak, too_strong;

    if(!as5600_get_status(&detected, &too_weak, &too_strong)) {
        state.magnet_state = MAGNET_STATE_UNKNOWN;
        return false;
    }

    if(detected) {
        if(too_weak) {
            state.magnet_state = MAGNET_STATE_TOO_WEAK;
        }
        else if(too_strong) {
            state.magnet_state = MAGNET_STATE_TOO_STRONG;
        }
        else {
            state.magnet_state = MAGNET_STATE_DETECTED;
        }
    } else {
        state.magnet_state = MAGNET_STATE_NOT_DETECTED;
    }

    return true;
}

bool update_magnet_angle()
{
    uint16_t angle;

    if(!as5600_get_angle(&angle)) {
        return false;
    }

    // check if the change is too large in either direction,
    // meaning the angle looped around across the zero position
    int32_t change = (angle - state.angle);
    if(change > 2048 || change < -2048) {
        if(state.angle > 2048) {
            // previous angle was close to max value (4096)
            // change = (angle + 4096) - state.angle;
            // e.g. state.angle=4000, angle=4, change=100
            state.full_turns += 1;
        }
        else {
            // previous angle was close to min value (0)
            // change = (angle - 4096) + state.angle;
            // e.g. state.angle=4, angle=4000, change=100
            state.full_turns -= 1;
        }
    }
    state.angle = angle;

    return true;
}

void note_last_updated_time()
{
    last_update = (clock_t) time_us_64() / 10000;
}

void update_loop()
{
    clock_t now = (clock_t) time_us_64() / 10000;
    if((now - last_update) * 1000 / CLOCKS_PER_SEC > UPDATE_INTERVAL_MS) {
        note_last_updated_time();

        state.filament_present = ir_sensor_value();

        if(!update_magnet_state()) {
            // state.health = HEALTH_AS5600_READ_FAILED;
            return;
        }

        if(!update_magnet_angle()) {
            // state.health = HEALTH_AS5600_READ_FAILED;
            return;
        }

        // state.health = HEALTH_OK;
    }
}

#define MEMCPY_REG_DATA(__buf, __data, __length) \
    { \
        __length = sizeof(__data); \
        memcpy(__buf, (uint8_t *)&__data, sizeof(__data)); \
    }

void prepare_register_data(uint8_t reg, uint8_t *buf, size_t *length)
{
    /* Zero first: the 0xff memset below runs unconditionally on *length
     * bytes when locked, so an unknown register with an uninitialised
     * length would turn into an out-of-bounds write into the caller's
     * buffer instead of just a bad frame. Every current caller already
     * zeroes length before calling, so this is a no-op for them - it just
     * makes the function safe on its own rather than relying on a
     * precondition that isn't written down anywhere. */
    *length = 0;

    if(rr_identity_registers_read(reg, buf, length))
        return;

    if(reg == READ_ALL) {
        MEMCPY_REG_DATA(buf, state, *length);
    // } else if(reg == READ_HEALTH) {
    //     MEMCPY_REG_DATA(buf, state.health, *length);
    } else if(reg == READ_MAGNET_STATE) {
        MEMCPY_REG_DATA(buf, state.magnet_state, *length);
    } else if(reg == READ_FILAMENT_PRESENCE) {
        MEMCPY_REG_DATA(buf, state.filament_present, *length);
    } else if(reg == READ_FULL_TURNS) {
        MEMCPY_REG_DATA(buf, state.full_turns, *length);
    } else if(reg == READ_ANGLE) {
        MEMCPY_REG_DATA(buf, state.angle, *length);
    }

    /* An unprovisioned board answers, but says nothing. Silence is not an
     * option: an I2C target that stops ACKing reads as a wiring fault and a
     * quiet TMC-UART reads as a dead board, and both send somebody hunting
     * hardware problems that do not exist. 0xff is out of range for every
     * field here - it is no defined MAGNET_STATE_*, no plausible presence
     * flag, and 0xffffffff is no plausible angle or turn count - so an
     * unpatched host reads visibly broken rather than plausibly wrong. */
    if(rr_identity_registers_locked())
        memset(buf, 0xff, *length);
}

int main() {
    struct rr_identity_store identity_store;

    rr_identity_pico_store_init(&identity_store);
    rr_usb_descriptors_init(&identity_store);
    stdio_init_all();
    rr_usb_admin_init_for_firmware(&identity_store);

    neopixel_init();
    sleep_ms(100);
    neopixel_solid(RED);

    // state.health = HEALTH_UNKNOWN;
    state.magnet_state = MAGNET_STATE_UNKNOWN;
    state.filament_present = false;
    state.full_turns = 0;
    state.angle = 0;
    note_last_updated_time();

    as5600_init();
    ir_sensor_init();

#if defined(IS_I2C_TARGET) && IS_I2C_TARGET
    i2c_target_init();
#elif defined(USB_SERIAL_COMMS) && USB_SERIAL_COMMS
    usbserial_init();
#else
    tmcuart_init();
#endif

    sleep_ms(1000);

    neopixel_solid(OFF);

    while (1) {
        tud_task();
        rr_usb_admin_poll();
        update_loop();

        if(rr_identity_registers_locked()
           && rr_identity_led_burst_active((uint32_t)(time_us_64() / 1000u))) {
            /* Between bursts the diagnostics own the LED completely. Because
             * PROVISION_UUID resets the board, the absence of amber on the
             * next boot is the success confirmation - visible with no host,
             * no tool and no serial console. */
            neopixel_blink(AMBER, RR_IDENTITY_LED_BLINK_MS);
        } else if(state.magnet_state != MAGNET_STATE_DETECTED) {
            neopixel_blink(RED, 100);
        } else if(!state.filament_present) {
            neopixel_solid(BLUE);
        } else {
            neopixel_solid(GREEN);
        }

        neopixel_loop();

#if defined(USB_SERIAL_COMMS) && USB_SERIAL_COMMS
        usbserial_loop();
#elif !defined(IS_I2C_TARGET) || !IS_I2C_TARGET
        tmcuart_loop();
#endif
    }
}

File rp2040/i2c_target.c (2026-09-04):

#include <stdio.h>

#include <hardware/i2c.h>
#include <pico/i2c_slave.h>
#include <pico/stdlib.h>

#include "i2c_target.h"

#define I2C_INST i2c0
#define I2C_SDA_PIN 4
#define I2C_SCL_PIN 5
#define I2C_BAUDRATE 100 * 1000 /* 100 kHz */
#define I2C_ADDRESS 0x40

static struct
{
    uint8_t mem[256];
    size_t mem_length;   /* bytes of mem[] valid for the current transaction */
    size_t mem_position; /* next byte of mem[] to serve on I2C_SLAVE_REQUEST */
    uint8_t mem_address;
    bool mem_address_written;
} context;

void prepare_register_data(uint8_t reg, uint8_t *buf, size_t *length);

static void i2c_slave_handler(i2c_inst_t *i2c, i2c_slave_event_t event) {
    switch (event) {
    case I2C_SLAVE_RECEIVE: // master has written some data
        if (!context.mem_address_written) {
            // writes always start with the memory address
            context.mem_address = i2c_read_byte_raw(i2c);
            context.mem_address_written = true;

            /* Cache the payload once, here, at the point the register
             * address becomes known - not per I2C_SLAVE_REQUEST below.
             * The TX FIFO (IC_TX_BUFFER_DEPTH) is 16 bytes, smaller than
             * some register payloads (up to 34 bytes), so RD_REQ re-fires
             * once per byte once the FIFO drains; re-running
             * prepare_register_data() on every one of those events would
             * rebuild the serial string ~34 times inside an ISR while the
             * bus clock-stretches. */
            context.mem_length = 0;
            context.mem_position = 0;
            prepare_register_data(context.mem_address, context.mem, &context.mem_length);
        } else {
            /* read and discard, we do not support I2C writes */
            i2c_read_byte_raw(i2c);
        }
        break;
    case I2C_SLAVE_REQUEST: // master is requesting data
        /* Serve one byte per event from the cached payload, advancing
         * mem_position. This is what makes a payload larger than the
         * 16-byte TX FIFO work: the master re-issues RD_REQ for every byte
         * it clocks out, and each call here answers exactly one of those,
         * rather than trying to push the whole payload in a single burst
         * that the FIFO would silently truncate. */
        if (context.mem_position < context.mem_length) {
            i2c_write_byte_raw(i2c, context.mem[context.mem_position]);
            context.mem_position++;
        } else {
            /* Past the end of the payload (or an unknown register, where
             * mem_length is 0): send a defined filler rather than walking
             * off the buffer or re-serving stale bytes. */
            i2c_write_byte_raw(i2c, 0x00);
        }
        break;
    case I2C_SLAVE_FINISH: // master has signalled Stop, or a repeated Start
        /* This also fires mid-transaction on a repeated START (e.g. between
         * the register-address write and the read that follows it), not
         * only on Stop. Do not reset mem_length or mem_position here: the
         * cached payload built in I2C_SLAVE_RECEIVE must survive into the
         * read phase. Only mem_address_written is reset, so the next write
         * is treated as a fresh register address; mem_length/mem_position
         * are re-armed there too, at the point a new address arrives. */
        context.mem_address_written = false;
        break;
    default:
        break;
    }
}

void i2c_target_init()
{
    gpio_init(I2C_SDA_PIN);
    gpio_set_function(I2C_SDA_PIN, GPIO_FUNC_I2C);
    gpio_pull_up(I2C_SDA_PIN);

    gpio_init(I2C_SCL_PIN);
    gpio_set_function(I2C_SCL_PIN, GPIO_FUNC_I2C);
    gpio_pull_up(I2C_SCL_PIN);

    i2c_init(I2C_INST, I2C_BAUDRATE);
    i2c_slave_init(I2C_INST, I2C_ADDRESS, &i2c_slave_handler);
}

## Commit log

2026-09-01 Add scripts for live data streaming and HTML visualization
    - Implemented `check_line_endings.py` to check and fix CRLF line endings in working-tree files.
    - Created `index.html` for the Roadrunner data visualization interface.
    - Developed `live.py` to handle live updates from the Moonraker server using WebSockets.
    - Added `main.py` to manage the application flow, including live data fetching and file writing.
    - Introduced `replay.py` for replaying saved sensor data from a file.
    - Established `server.py` to set up an HTTP server and WebSocket communication for data streaming.
    - Added `requirements.txt` to specify necessary Python packages.
    - Created `moonraker-update-manager.conf` for configu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
    [Roadrunner_body-6pin jst-ph.step]
2026-09-01 Enhance error logging in I2C reader and add regression test for transport failures - Updated RegisterReaderI2C to include sensor name in error messages - Added regression test for I2C read failures t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
    [high_resolution_filament_sensor.py]
2026-09-02 fix: reserve usb cdc for protocol frames
    [main.c]
2026-09-02 docs: tag the admin-frame code block as c
2026-09-02 fix: correct stale identity docs and cover full CDC-stdio guard
    CLEAR_IDENTITY already shipped in 9ced66e, so stop describing it as
    forthcoming in README.md, and update rp2040/README.md's bench-validation
    section to record the 2026-09-02 provisioning/clear/UF2-retention/refusal
    results instead of claiming they are unrecorded.
    Extend check_protocol_only_stdio.cmake to grep every project source file
    that can be linked into a USB-CDC-stdio-enabled image, not just main.c.
    This surfaced a real violation: tmcuart.c's bad-CRC diagnostic printf runs
    in both UART images, which also enable USB CDC stdio for the admin
    protocol, so it could interleave with protocol frames on the same CDC
    interface. Dro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
    [tmcuart.c]
2026-09-03 fix: serve i2c register reads one byte per request
    The 16-byte TX FIFO silently drops bytes beyond its depth when a whole
    payload is pushed in one burst; the master's RD_REQ then re-fires from an
    empty FIFO and repeats the handler from byte 0. Task 1's serial (34) and
    firmware version (32) registers are the first payloads to exceed the FIFO,
    so 0x31 and 0x32 read back truncated and repeating. Cache the payload once
    per transaction, when the register address is written, and serve it from
    an advancing index so each RD_REQ answers exactly one byte.
    [i2c_target.c]
2026-09-03 feat: refuse sensor registers until the board is provisioned
2026-09-03 fix: zero-init prepare_register_data length before the 0xff gate
    [main.c]
2026-09-03 feat: announce an unprovisioned board with a periodic amber burst
2026-09-03 fix: ungate REBOOT_BOOTSEL so a conflicted board can still recover
    rr_identity_clear() refuses to erase a genuinely conflicted sector, so
    gating REBOOT_BOOTSEL on RR_IDENTITY_OK (from Task 3) left a conflicted
    board with no software recovery path at all: every opcode but INFO
    returned an error. REBOOT_BOOTSEL is maintenance, not the sensor-serving
    behaviour the identity invariant protects, and normal UF2 updates
    preserve the identity sector, so removing the gate is not an identity
    bypass. CLEAR_IDENTITY's own gate (refused only from RR_IDENTITY_NONE)
    is unchanged.
    Also corrects three documentation inaccuracies caught in review: the
    protocol doc claimed CLEAR_IDENTITY recovers a CONFLICT, wh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
2026-09-03 docs: correct a false CLEAR_IDENTITY rationale and a misnamed test
    The CLEAR_IDENTITY gate comment in usb_admin.c claimed CONFLICT is a
    state clear recovers from; identity_store.c refuses to erase a
    conflicted sector before any recovery is attempted, so the gate admits
    the opcode but the store refuses it. Rewrote the comment to say so and
    to name REBOOT_BOOTSEL as the actual recovery path, without touching
    the gate condition itself.
    Renamed test_usb_admin_allows_clear_to_repair_a_conflict to
    test_usb_admin_clear_gate_admits_a_non_none_status: it only fakes the
    cached identity_status to exercise the opcode gate, since the harness
    never puts the underlying store into a genuine two-slot disagr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
2026-09-04 fix: stop I2C_SLAVE_FINISH from zeroing the cached register payload
    I2C_SLAVE_FINISH fires mid-transaction on a repeated START, between the
    register-address write and the read that follows it, not only on Stop.
    Zeroing mem_length/mem_position there destroyed the payload cached in
    I2C_SLAVE_RECEIVE before any RD_REQ could serve it, so every I2C register
    read (both variants) clocked out 0x00 - including READ_IDENTITY_STATE,
    making the identity gate unreadable on a provisioned board.
    Also:
    - doc the blink rate's CLOCKS_PER_SEC==100 toolchain dependency
    - correct docs listing ALREADY_PROVISIONED (3) as an observable
    READ_IDENTITY_STATE/INFO value, which rr_identity_load() never returns
    - desc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
    [i2c_target.c]
2026-09-04 test: drive the i2c register state machine off-target
    Both bugs this handler has shipped were event-sequencing faults reachable
    only from a bench board: bursting a 34-byte payload past the 16-byte TX
    FIFO, and then destroying the cached payload in I2C_SLAVE_FINISH, which
    the SDK also raises on the repeated START in the middle of an ordinary
    write-address-then-read transaction.
    Neither needed hardware to reproduce, only an honest model of when the
    SDK delivers each event. Minimal stub headers stand in for the three SDK
    headers i2c_target.c includes, and the test #includes the file rather
    than linking it so the firmware keeps its file-static handler.
    Verified by mutation: reintroducing eithe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
    [test_i2c_target.c]
